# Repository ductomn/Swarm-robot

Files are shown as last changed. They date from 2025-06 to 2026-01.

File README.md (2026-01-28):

# Swarm Robot Platform

A low-cost, scalable swarm robotic platform designed for research and educational purposes, capable of infrared (IR)-based communication and basic cooperative behaviors.

Playlist of videos showcasing robots and algorithms: https://www.youtube.com/playlist?list=PLNTM9zCJujTltedypfpow2rPiPkVAqfGI

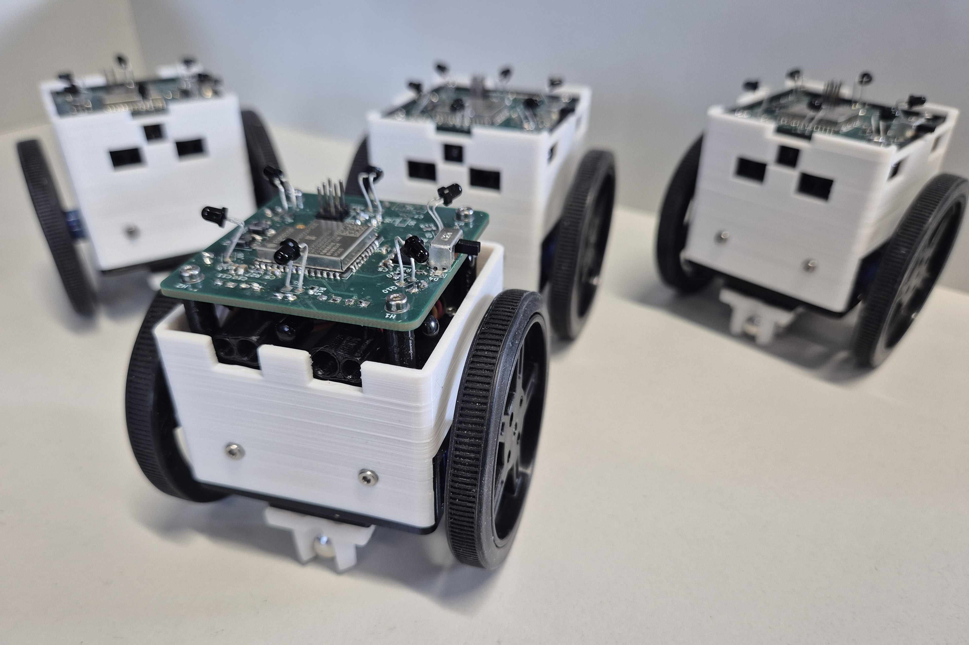
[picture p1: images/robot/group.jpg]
Swarm Robot


---

## 🧠 About the Project

This project focuses on the design of a **cooperative robotic platform** built around the ESP32 microcontroller. The primary goal is to enable simple, local communication and decentralized coordination among identical robots, forming a **swarm**.

**Key design constraints:**
- Minimal production cost (~24 EUR/robot, parts only)
- Compact and robust mechanical design
- Infrared-based full-duplex communication (360°)
- Modular and scalable C firmware using ESP-IDF
- Developed as part of a Bachelor’s Thesis at Brno University of Technology

> **Thesis Title:**  
> *Návrh a realizace kooperativní robotické platformy s jednoduchou komunikací*  
> (*Design and Implementation of a Cooperative Robotic Platform with Simple Communication*)

---

## ⚙️ Features

### 🔁 360° IR Communication
6 pairs of IR LEDs and phototransistors evenly placed around the robot enable full directional communication.

### 🚧 Obstacle Detection
2 front-facing IR LED + phototransistor pairs detect obstacles.

### 🤖 Cooperative Algorithms

#### With Leader
- Simulates a robot "calling" others to complete a task.
- Modified CSMA/CA protocol ensures robots check for ongoing transmissions before broadcasting.
- Robots walk randomly looking for signals:
  - If signal is found in a randomly chosen time window → the robot becomes a **follower**.
  - If not → the robot becomes a **leader**.
- **Leader** can be pre-set (WITH_LEADER 1)

- **Flowchart of system with leader:**

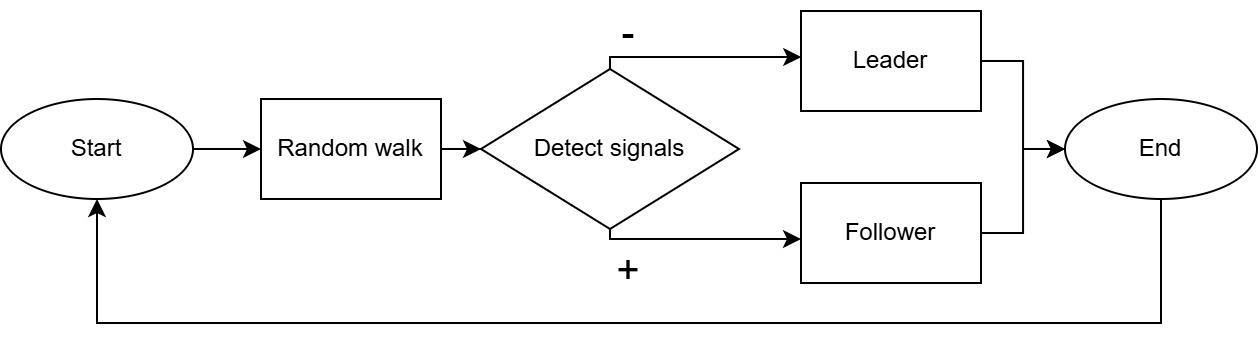
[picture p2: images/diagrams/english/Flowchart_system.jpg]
Flowchart


- **Implemented algorithms:**

  - **Follow**  
    Followers track the leader, who moves randomly.  
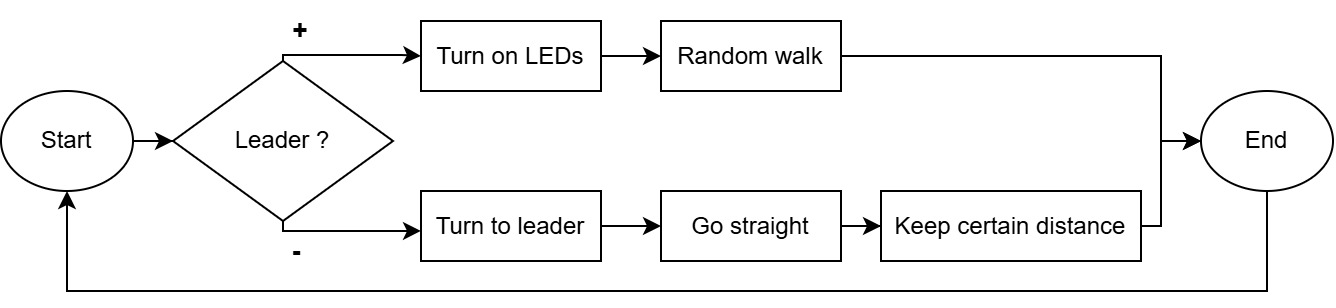
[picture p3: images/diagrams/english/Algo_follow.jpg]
Follow
    
  
  - **Spread Out**  
    Leader stays in place and acts as a beacon. Followers spread and return.  
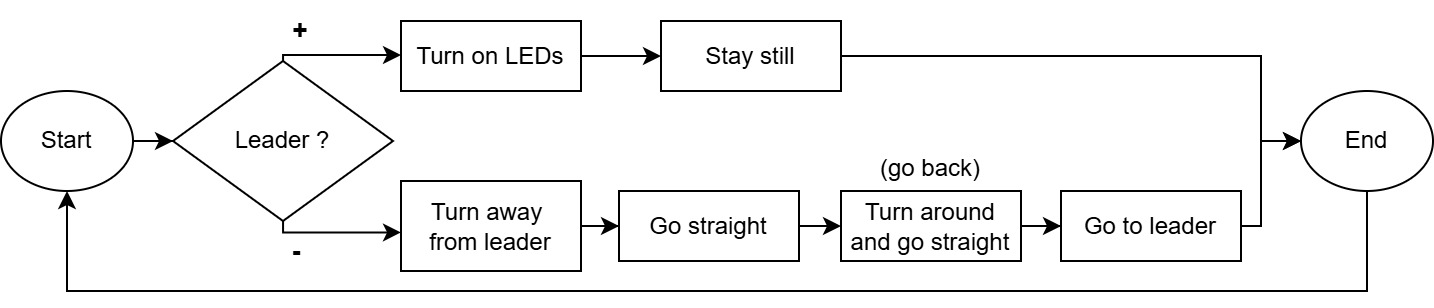
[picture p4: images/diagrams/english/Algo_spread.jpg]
Spread
    

#### Without Leader
- No signal detection or leader election.
- Algorithms run immediately after power-on.
  
- **Implemented algorithms:**

  - **Follow Chain**  
    Robots follow each other in a line. First robot walks randomly. Predefined or dynamic ID (order) assignment.  
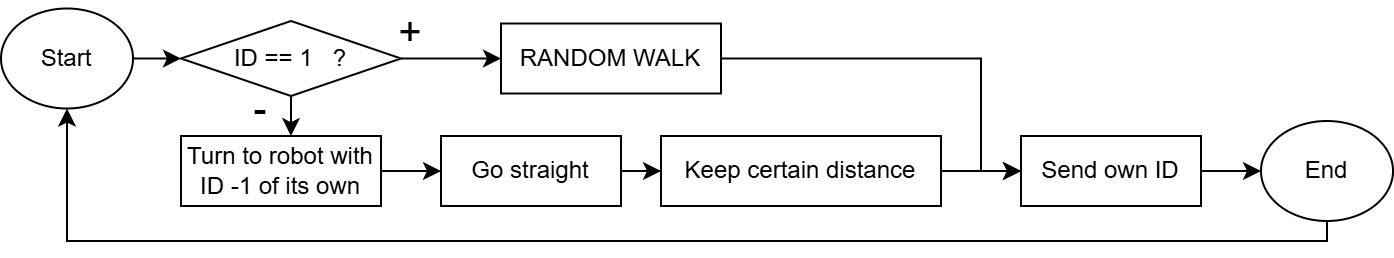
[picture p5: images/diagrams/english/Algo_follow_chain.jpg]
Follow Chain
    
  
  - **Chain**  
    Robots stay still in a line. The last robot moves forward to the front.  
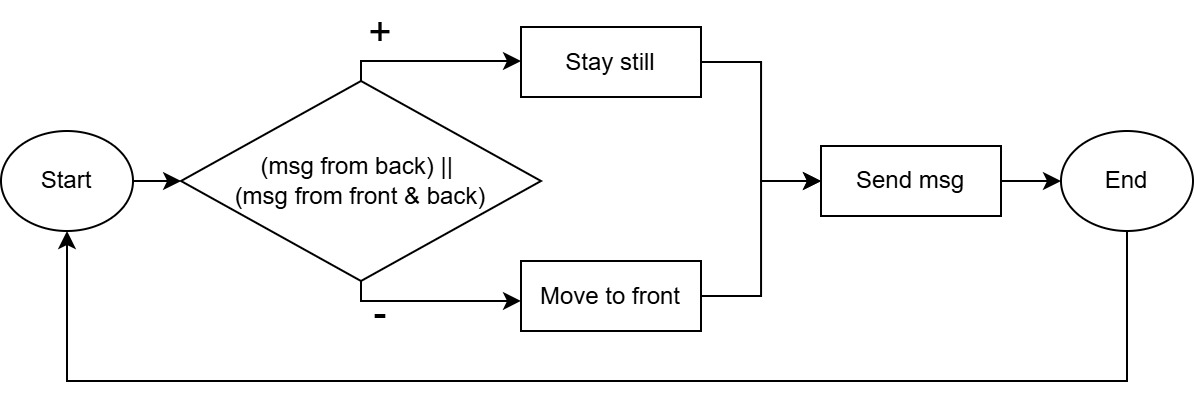
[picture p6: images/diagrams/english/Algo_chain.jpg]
Chain
    

### 🧠 FSM-Controlled Behavior

Each robot uses a finite state machine (FSM) for autonomous control and decision-making. The diagram shows the flow of states of algorithms with leader.  

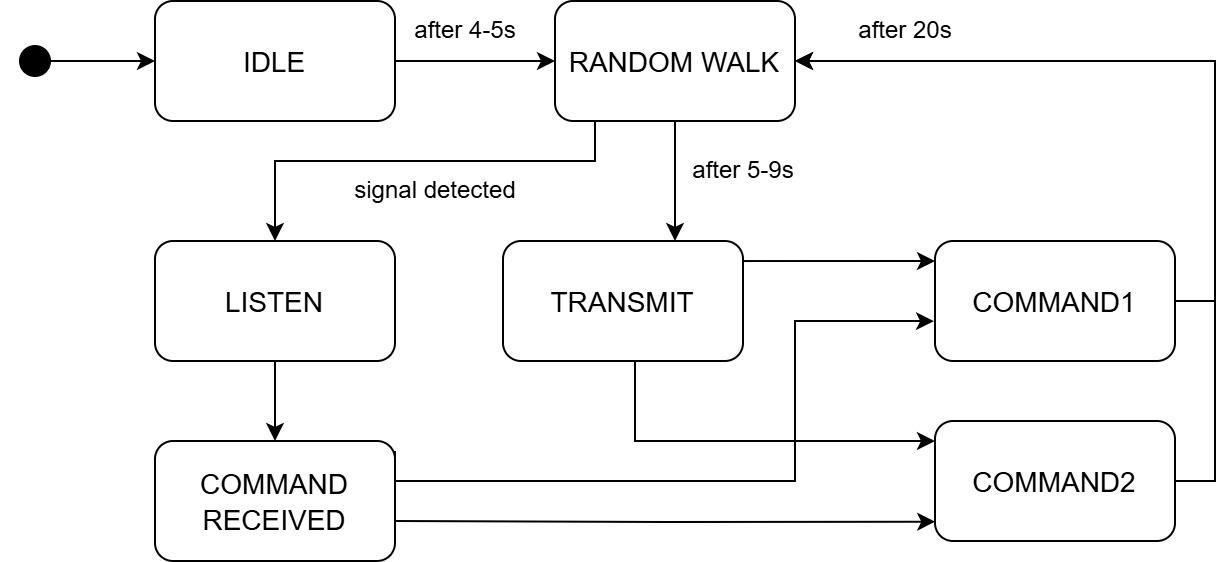
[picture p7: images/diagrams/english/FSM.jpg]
FSM Diagram


### 🔧 Firmware Modules

- `io_define` – I/O pin mappings, robot ID
- `servo_driver` – movement (servo) control
- `led_driver` – IR LED driver
- `hwtimer` – Hardware timer driver
- `adc_lib` – ADC driver
- `dm_comm` – IR communication (Manchester encoding, CSMA/CA)
- `coop` – Cooperative algorithm logic
- `state_machine` – FSM and behavior transitions

---

## 🛠️ Setting Up

### Requirements

- [ESP-IDF](https://docs.espressif.com/projects/esp-idf/en/latest/esp32/)
- PlatformIO (recommended; VS Code plugin)  
  Target board: `ESP32DOIT-DEVKIT-V1`
- USB-to-UART bridge (e.g. CP2102)

### 🔧 Calibration  

- **Movement Calibration**  
  The robot doesn’t use encoders, so the motors may spin at different speeds, causing drift.  
  Adjust `SERVO_FORWARD_LEFT_MOD` and `SERVO_BACKWARDS_RIGHT_MOD` in `io_define.h` to straighten movement.

- **IR Signal Thresholds**  
  Tune `SIG_THRESHOLD` in `dm_comm.h` and `DIS_THRESHOLD` in `coop.h` to adjust signal sensitivity.

- **Algorithm Selection**  
  Some algorithms (like **Chain** or **Follow Chain**) should start immediately on power-up.  
  Define the startup behavior by setting flags to "1" (`CHAIN` or `FOLLOW_CHAIN`).

### ⚡ Flashing Instructions  

1. Connect the robot to your computer via USB.
2. Open `io_define.h` and set:
   - `ROBOT_ID` – unique number per robot
   - `WITH_LEADER` – `1` (for pre-set leader - ID1) or `0`
   - `CHAIN` or `FOLLOW_CHAIN` – chosen algorithm
3. Build and flash the firmware

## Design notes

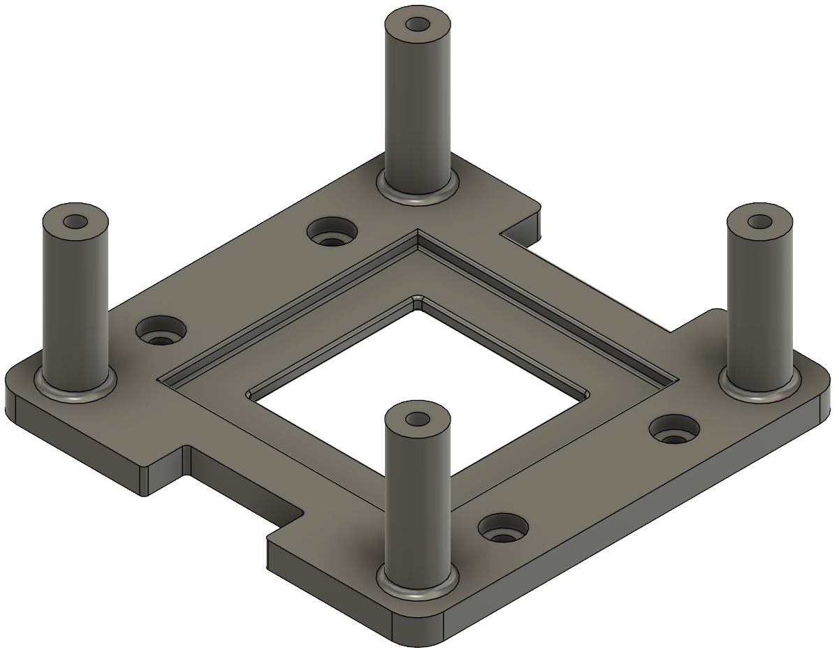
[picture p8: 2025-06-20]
images/robot/robot_Chassis_top v10.png

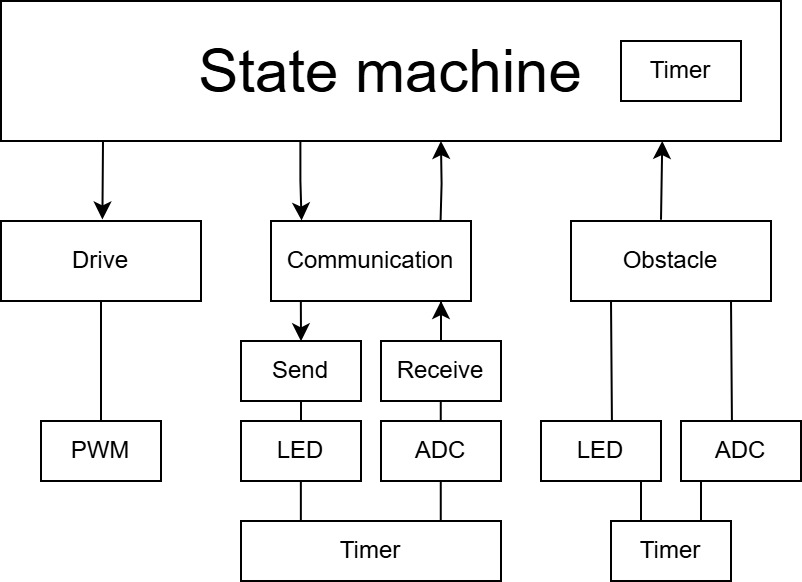
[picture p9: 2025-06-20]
images/diagrams/english/Software_architecture.jpg

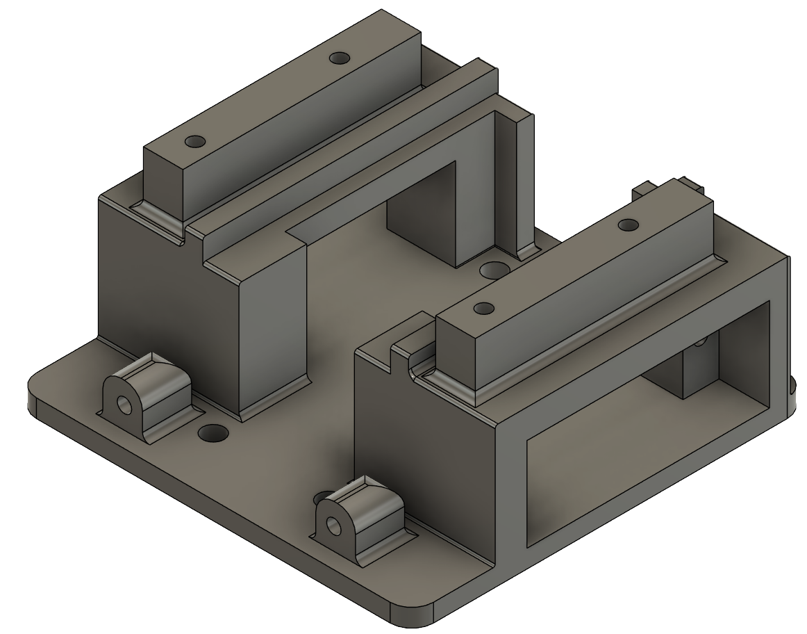
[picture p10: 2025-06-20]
images/robot/robot_Chassis_bottom.png

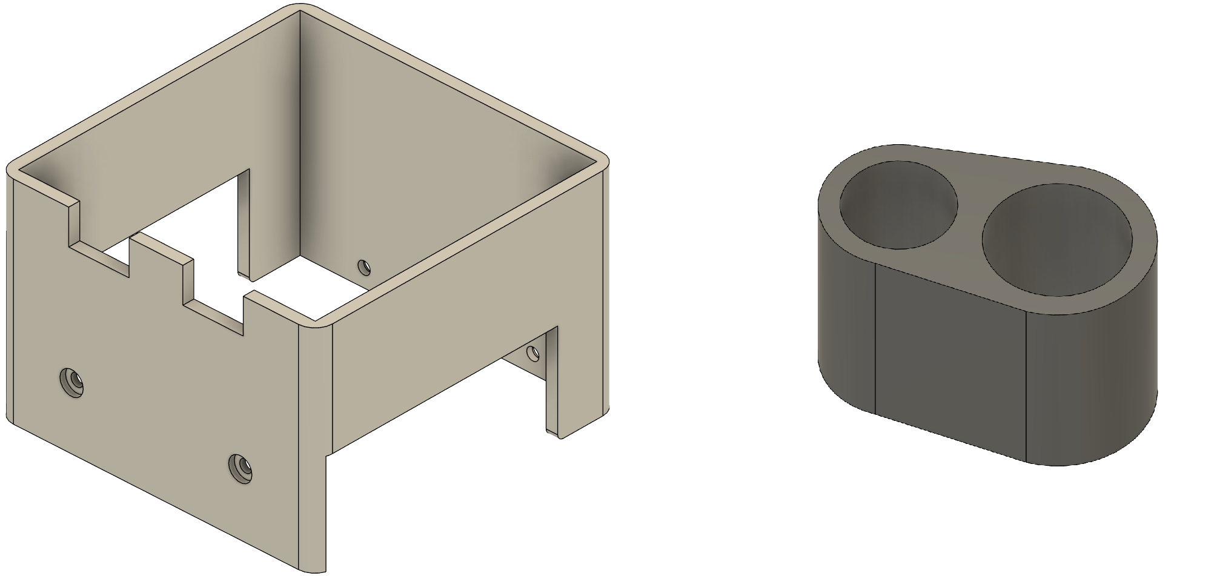
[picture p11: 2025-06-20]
images/robot/cover_LED_bottom.png

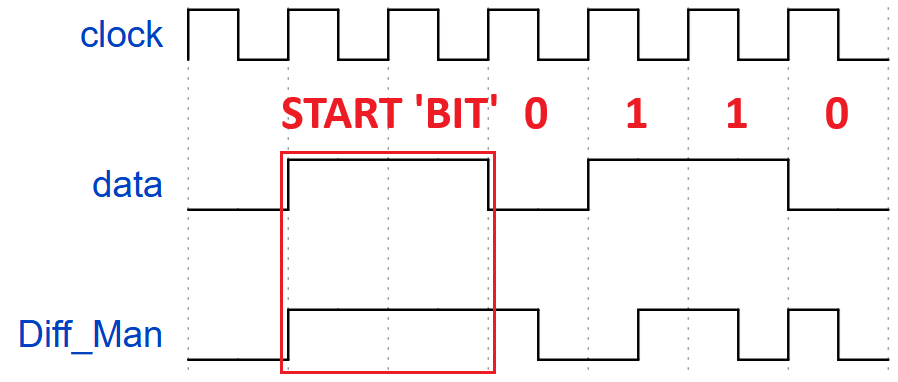
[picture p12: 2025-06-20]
images/diagrams/diff_man.png

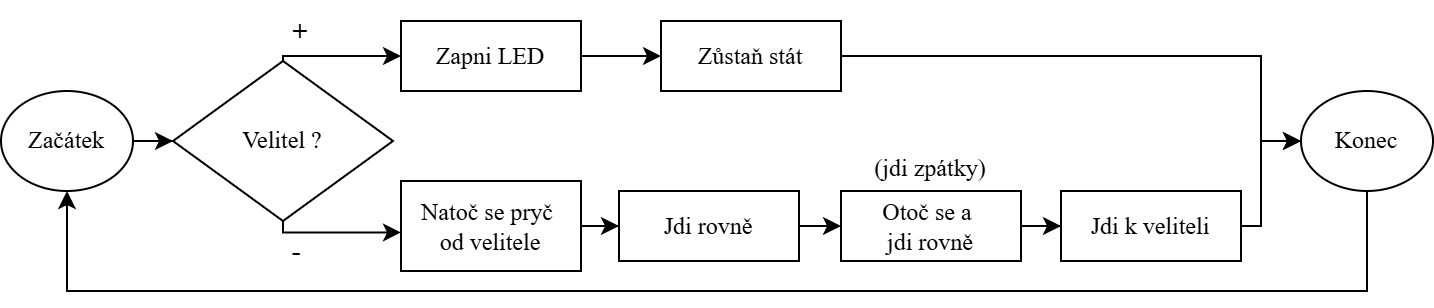
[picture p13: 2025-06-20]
images/diagrams/czech/Algo_spread.jpg

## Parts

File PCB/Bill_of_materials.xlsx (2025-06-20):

Reference | Value | Datasheet | Footprint | Qty | DNP | Total
C1,C2 | 22uF | ~ | Capacitor_SMD:C_1210_3225Metric_Pad1.33x2.70mm_HandSolder | 2 | x | #VALUE! | Laskakit
C3,C4,C7 | 10uF | ~ | -- mixed values -- | 3 | x+C7 | C7 | Hadex
C5,C6 | 0.1uF | ~ | Capacitor_SMD:C_0603_1608Metric_Pad1.08x0.95mm_HandSolder | 2 | 1 | 2
Comms1 | Jumper lišta |  | Connector_PinHeader_2.54mm:PinHeader_2x03_P2.54mm_Vertical | 1 | 3 | 3
D1 | D_Schottky | ~ | Diode_SMD:D_SMC | 1 | x | 0
D2 | LED_Blue? | ~ | LED_SMD:LED_0603_1608Metric | 1 | 0.8 | 0.8
D3 | LED_RED | ~ | LED_SMD:LED_0603_1608Metric | 1 | x | 0
D4 | LED_GREEN | ~ | LED_SMD:LED_0603_1608Metric | 1 | x | 0
IR0,IR1,IR2,IR3,IR4,IR5,IR6,IR7,IR8,IR9 | IR333C | ~ | LED_THT:LED_D1.8mm_W3.3mm_H2.4mm | 10 | 3 | 30
J1 | Li-Po 3.7V_1000mAh? |  | Connector_JST:JST_PH_S2B-PH-SM4-TB_1x02-1MP_P2.00mm_Horizontal | 1 | 99 | 99
J2,J3 | Motor | ~ | Personal:Cable_connector_WJ500V-5.08-2P | 2 | 17 | 34
L1 | 4.7uH | ~ | Inductor_SMD:L_Chilisin_BMRx00060630 | 1 | x | 0
Q1,Q12 | SI2312CDS | ~ | Package_TO_SOT_SMD:SOT-23 | 2 | 3.8 | 7.6
Q2,Q3,Q4,Q5,Q6,Q7,Q8,Q9,Q10,Q11 | PT334 | https://www.rcscomponents.kiev.ua/datasheets/bpw40.pdf | LED_THT:LED_D1.8mm_W3.3mm_H2.4mm | 10 | 3 | 30
R1 | 16k | ~ | Capacitor_SMD:C_0603_1608Metric_Pad1.08x0.95mm_HandSolder | 1 | x | 0
R2 | 2k2 | ~ | Capacitor_SMD:C_0603_1608Metric_Pad1.08x0.95mm_HandSolder | 1 | x | 0
R3 | 220 | ~ | Resistor_SMD:R_0603_1608Metric_Pad0.98x0.95mm_HandSolder | 1 | 0.8 | 0.8
R4 | 1k2 | ~ | Capacitor_SMD:C_0603_1608Metric_Pad1.08x0.95mm_HandSolder | 1 | x | 0
R5,R6 | 1k | ~ | Capacitor_SMD:C_0603_1608Metric_Pad1.08x0.95mm_HandSolder | 2 | x | 0
R7,R8,R9,R10,R11,R12,R13,R14 | 39 | ~ | Resistor_SMD:R_0603_1608Metric_Pad0.98x0.95mm_HandSolder | 8 |  | 0
R15,R29 | 100 | ~ | Resistor_SMD:R_0603_1608Metric_Pad0.98x0.95mm_HandSolder | 2 | 0.8 | 1.6
R16,R30 | 47k | ~ | Resistor_SMD:R_0603_1608Metric_Pad0.98x0.95mm_HandSolder | 2 | 0.8 | 1.6
R17,R18,R19,R20,R21,R22,R23,R24,R25,R26 | 4k7 | ~ | Resistor_SMD:R_0603_1608Metric_Pad0.98x0.95mm_HandSolder | 10 | 0.8 | 8
R27,R28 | 20 | ~ | Resistor_SMD:R_0603_1608Metric_Pad0.98x0.95mm_HandSolder | 2 |  | 0
SW1 | SW_SPST | ~ | Connector_PinHeader_2.54mm:PinHeader_1x02_P2.54mm_Vertical | 1 |  | 0
U2 | TB6612FNG | https://toshiba.semicon-storage.com/us/product/linear/motordriver/detail.TB6612FNG.html | Package_SO:SSOP-24_5.3x8.2mm_P0.65mm | 1 | 122 | 122
U3 | MT3608 | https://www.olimex.com/Products/Breadboarding/BB-PWR-3608/resources/MT3608.pdf | Package_TO_SOT_SMD:SOT-23-6 | 1 | 9 | 9
U4 | TP4056 | https://eu.mouser.com/datasheet/2/830/TP4056-2487427.pdf | Package_SO:SOP-8_3.9x4.9mm_P1.27mm | 1 | 9 | 9
U1 | module_ESP32 |  | Personal:ESP32-NodeMCU | 1 | 198 | 198 | chip_ESP32 | chip_ESP32
 |  |  |  |  |  | 556.4 | ams1117 | ams1117
 |  |  |  |  |  |  | cp2102 | CH340
 |  |  |  |  |  |  | další věci | další věci

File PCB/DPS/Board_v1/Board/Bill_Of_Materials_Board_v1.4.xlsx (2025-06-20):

Reference | Value | Datasheet | Footprint | Qty | DNP | Total
C1,C2 | 22uF | ~ | -- mixed values -- | 2 | x | 0 |  | Laskakit
L1 | 4.7uH | ~ | Inductor_SMD:L_Chilisin_BMRx00060630 | 1 | x | 0 |  | Mouser
D1 | D_Schottky | ~ | Diode_SMD:D_SMC | 1 | x | 0
J2 | USB_B_Micro | ~ | Connector_USB:USB_Micro-B_Amphenol_10118194-0001LF_Horizontal | 1 | x | 0
R22 | 2k2 | ~ | Capacitor_SMD:C_0603_1608Metric_Pad1.08x0.95mm_HandSolder | 1 | x | 0 |  | TOTAL:
U1 | MT3608 | https://www.olimex.com/Products/Breadboarding/BB-PWR-3608/resources/MT3608.pdf | Package_TO_SOT_SMD:SOT-23-6 | 1 | x | 0 |  |  | 610.249
C3,C4 | 10uF | ~ | -- mixed values -- | 2 | x | 0
R23 | 1k2 | ~ | Capacitor_SMD:C_0603_1608Metric_Pad1.08x0.95mm_HandSolder | 1 | x | 0
R24,R25 | 1k | ~ | -- mixed values -- | 2 | x | 0
D2 | LED_RED | ~ | LED_SMD:LED_0603_1608Metric_Pad1.05x0.95mm_HandSolder | 1 | x | 0
D3 | LED_GREEN | ~ | LED_SMD:LED_0603_1608Metric_Pad1.05x0.95mm_HandSolder | 1 | x | 0
U2 | TP4056 | https://eu.mouser.com/datasheet/2/830/TP4056-2487427.pdf | Package_SO:SOP-8_3.9x4.9mm_P1.27mm | 1 | 18 | 18
C5, C6 | 10uF | ~ | 0603_1608 | 2 | 1.13 | 2.26 | x
C7,C8,C9,C11 | 0.1uF | ~ | Capacitor_SMD:C_0603_1608Metric_Pad1.08x0.95mm_HandSolder | 4 | 0.376 | 1.504 | x
C10 | 22uF | ~ | Capacitor_SMD:C_0603_1608Metric_Pad1.08x0.95mm_HandSolder | 1 | 1.75 | 1.75 | x
Comms1 | ~ |  | Connector_PinHeader_2.54mm:PinHeader_2x03_P2.54mm_Vertical | 1 | 3 | 3
D6 | ESD5Z5.0T1G | https://www.onsemi.com/pdf/datasheet/esd5z2.5t1-d.pdf | Diode_SMD:D_SOD-523 | 1 | 3.33 | 3.33 | x
D5 | 1N5819HW-7-F | ~ | Diode_SMD:D_SOD-123 | 1 | 5.96 | 5.96 | x
D4 | LED | ~ | LED_SMD:LED_0603_1608Metric_Pad1.05x0.95mm_HandSolder | 1 | 0.8 | 0.8 | x
IR1,IR2 | SFH4544 | ~ | LED_THT:LED_D1.8mm_W3.3mm_H2.4mm | 2 | 13.33 | 26.66 | x
IR3,IR4,IR5,IR6,IR7,IR8 | SFH4547 | ~ | LED_THT:LED_D1.8mm_W3.3mm_H2.4mm | 6 | 6.57 | 39.42 | x
J1 | Li-Po 3.7V_1000mAh |  | Connector_JST:JST_PH_S2B-PH-SM4-TB_1x02-1MP_P2.00mm_Horizontal | 1 | 99 | 99 | x
 | Konektor _Baterie |  |  | 1 | 2 | 2 | x
M1,M2 | Servo_Motor SG90 | ~ |  | 2 | 60 | 120 | x
 | Konektor |  | Connector_PinHeader_2.54mm:PinHeader_1x03_P2.54mm_Vertical | 2 | 0.8 | 1.6
Q5,Q6,Q7,Q8,Q9,Q10 | TEFT4300 | https://www.rcscomponents.kiev.ua/datasheets/bpw40.pdf | LED_THT:LED_D1.8mm_W3.3mm_H2.4mm | 6 | 9.3 | 55.8 | x
Q1,Q2 | 304PTD4B-1A |  |  | 2 | 2.8 | 5.6
Q3,Q4 | SI2312CDS | ~ | Package_TO_SOT_SMD:SOT-23 | 2 | 3.8 | 7.6 | x
R1,R2,R15,R16,R17,R18,R19,R20 | 4k7 | ~ | Resistor_SMD:R_0603_1608Metric_Pad0.98x0.95mm_HandSolder | 8 | 0.376 | 3.008 | x
R3,R4,R7,R8,R9,R10,R11,R12 | 39 | ~ | Resistor_SMD:R_0603_1608Metric_Pad0.98x0.95mm_HandSolder | 8 | 0.326 | 2.608 | x
R5,R13 | 100 | ~ | Resistor_SMD:R_0603_1608Metric_Pad0.98x0.95mm_HandSolder | 2 | 0.2 | 0.4 | x
R6,R14 | 47k | ~ | Resistor_SMD:R_0603_1608Metric_Pad0.98x0.95mm_HandSolder | 2 | 0.226 | 0.452 | x
R21 | 16k | ~ | Capacitor_SMD:C_0603_1608Metric_Pad1.08x0.95mm_HandSolder | 1 | 0.2 | 0 | x
R27 | 10k | ~ | Resistor_SMD:R_0603_1608Metric_Pad0.98x0.95mm_HandSolder | 1 | 0.301 | 0.301 | x
R26 | 5k1 | ~ | Resistor_SMD:R_0603_1608Metric_Pad0.98x0.95mm_HandSolder | 1 | 0.326 | 0.326 | x
SW1 | SLW-864574-5A-RA-N-D | ~ | Button_Switch_THT:SW_Slide_SPDT_Straight_CK_OS102011MS2Q | 1 | 7.87 | 7.87 | x
SW2,SW3 | TS-1088R-02026 | ~ | 0_Custom_Footprints:SW_Tactile_TS-1088R-02026 | 2 | 3 | 6 | x
U3 | AMS1117-3.3 | http://www.advanced-monolithic.com/pdf/ds1117.pdf | Package_TO_SOT_SMD:SOT-223-3_TabPin2 | 1 | 3 | 3 | x
U4 | ESP32-WROOM-32UE | https://www.espressif.com/sites/default/files/documentation/esp32-wroom-32e_esp32-wroom-32ue_datasheet_en.pdf | RF_Module:ESP32-WROOM-32D | 1 | 68 | 68 | x
kolo sg90 |  |  |  | 2 | 38 | 76 | x
podperné kolo |  |  |  | 2 | 24 | 48 | x
 |  |  |  | 82

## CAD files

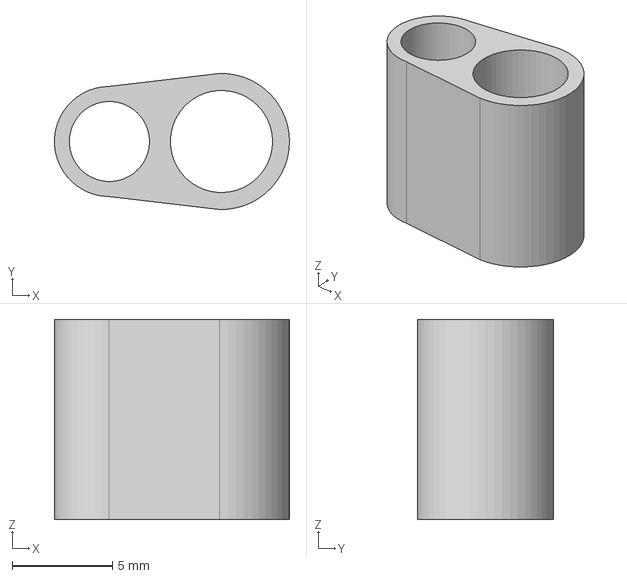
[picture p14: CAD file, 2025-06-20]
3D_model/LED_cover_both.step
11.7 x 6.80 x 10.0 mm

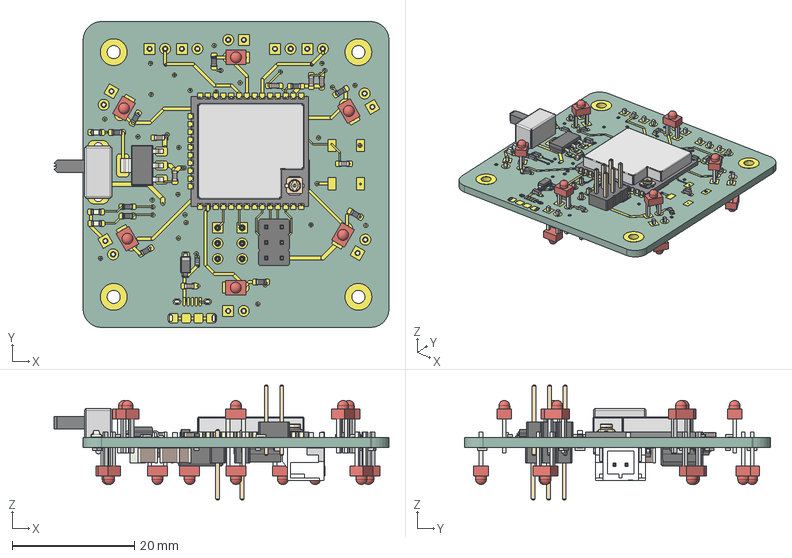
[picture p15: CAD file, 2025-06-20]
PCB/DPS/Board_v1/Board/Board.step
54.8 x 50.0 x 18.8 mm
LED_0603_1608Metric x 3
C_0603_1608Metric x 7
D_SOD_523
R_0603_1608Metric x 27
SOT_223
LED_D1.8mm_W3.3mm_H2.4mm x 16
D_SOD_123
ESP32-WROOM-32U
PinHeader_2x03_P254mm_Vertical
SLW-864574-5A-RA-N-D
CQ assembly
C_1210_3225Metric x 4
SOT_23 x 2
D_SMC
JST - PH - SMD (R) - 2Pin - 2.00mm
PinHeader_1x03_P254mm_Vertical x 2
SOT_23_6
Board_track_1
Board_track_2
Board_track_3
Board_track_4
Board_track_5
Board_track_6
Board_track_7
Board_track_8
Board_track_9
Board_track_10
Board_track_11
Board_track_12
Board_track_13
Board_track_14
Board_track_15
Board_track_16
Board_track_17
Board_track_18
Board_track_19
Board_track_20
Board_track_21
Board_track_22
Board_track_23
Board_track_24
Board_track_25
Board_track_26
Board_track_27
Board_track_28
Board_track_29
Board_track_30
Board_track_31
Board_track_32
Board_track_33
Board_track_34
Board_track_35
Board_track_36
Board_track_37
Board_track_38
Board_track_39
Board_track_40
Board_track_41
Board_track_42
Board_track_43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

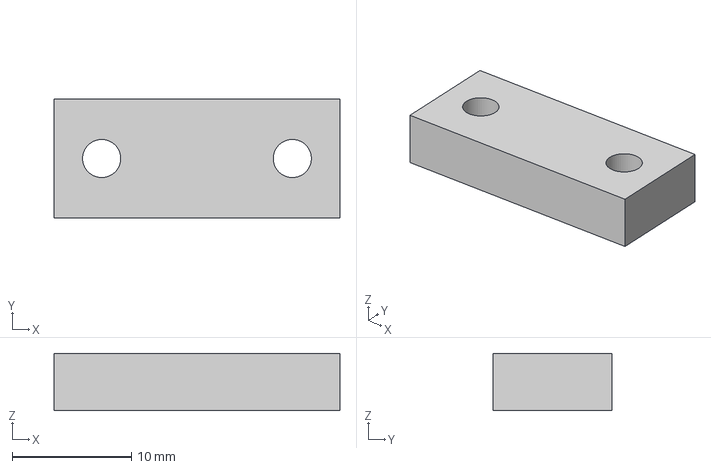
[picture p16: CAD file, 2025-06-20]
3D_model/Castor_support.step
24.0 x 10.0 x 4.80 mm

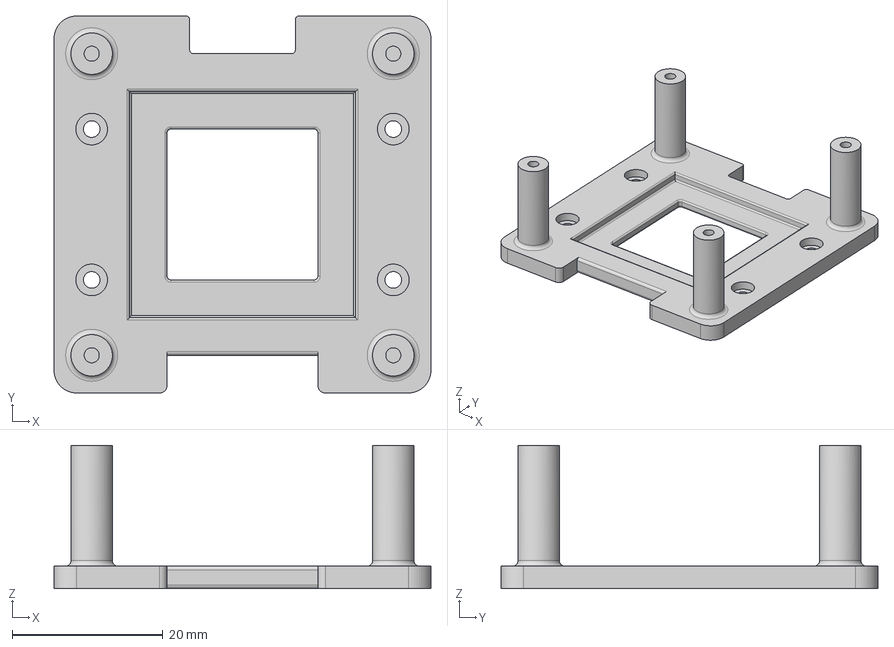
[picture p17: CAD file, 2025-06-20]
3D_model/Chassis_top.step
50.0 x 50.0 x 19.0 mm

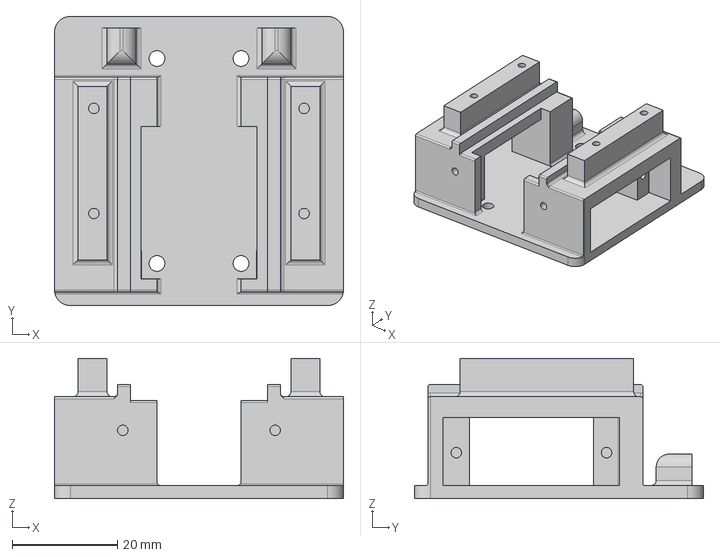
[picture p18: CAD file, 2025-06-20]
3D_model/Chassis_bottom.step
55.0 x 55.0 x 26.7 mm

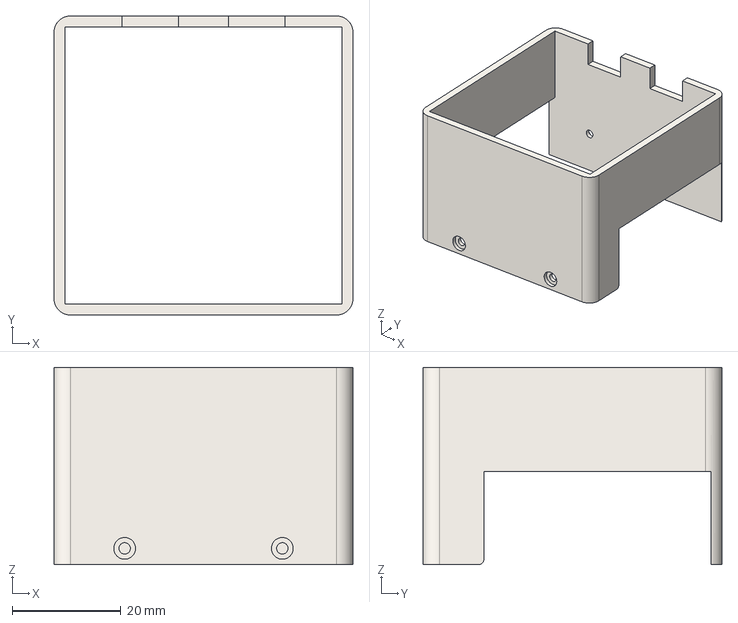
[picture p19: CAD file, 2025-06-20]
3D_model/Cover_bottom_without_LED.step
55.0 x 55.0 x 36.3 mm

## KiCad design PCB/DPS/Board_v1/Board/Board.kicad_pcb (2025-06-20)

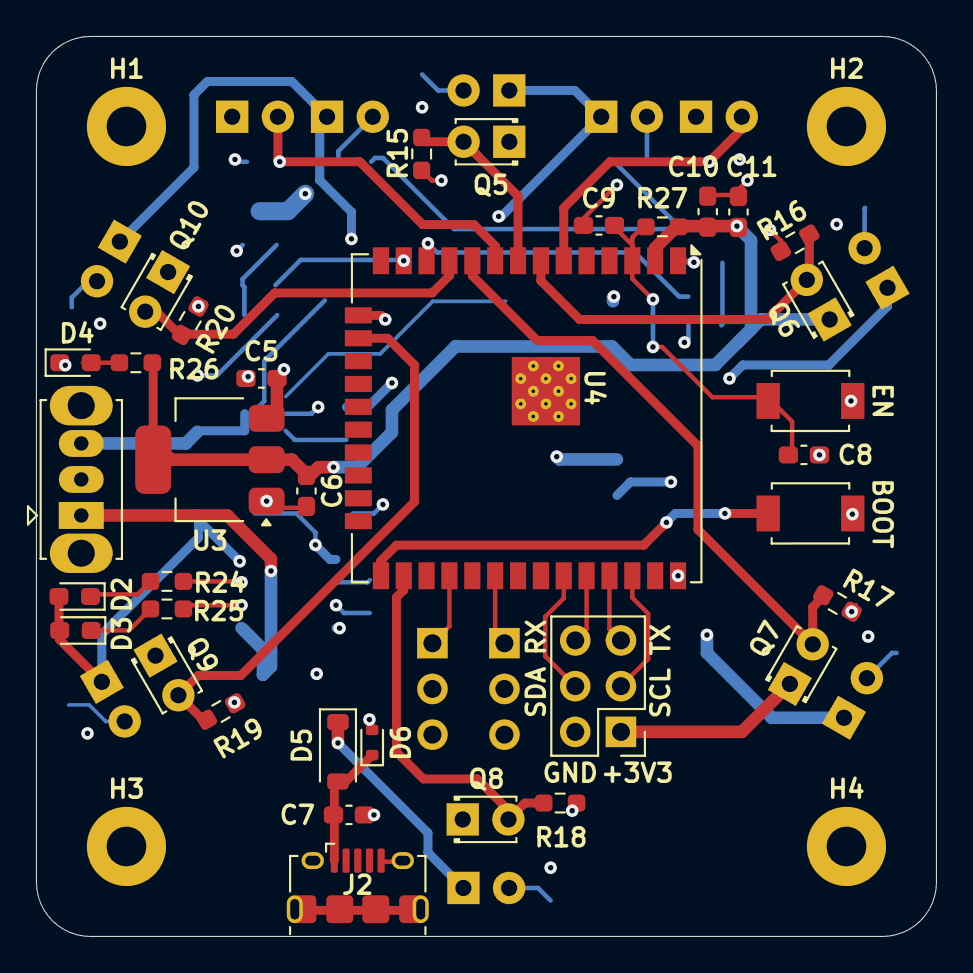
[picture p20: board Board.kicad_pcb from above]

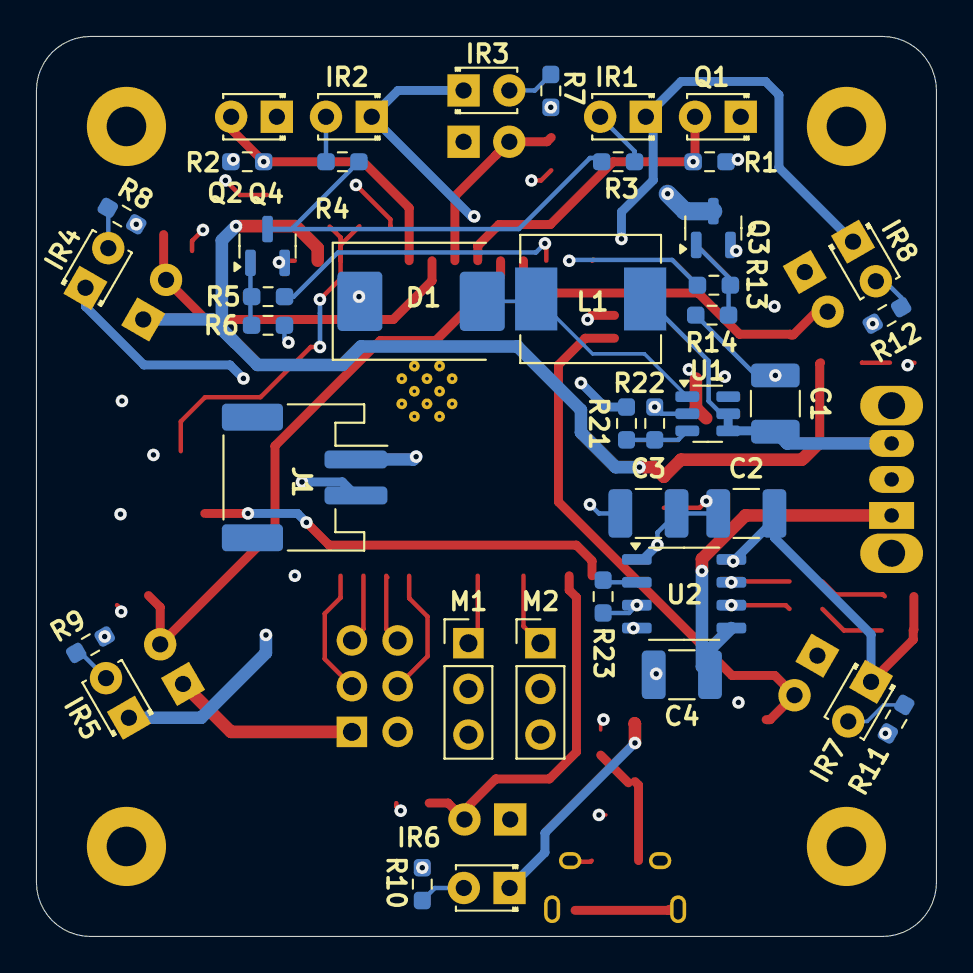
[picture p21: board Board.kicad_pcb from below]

Board: 4 copper layers, 50.0 x 50.0 mm, 79 parts (40 on the bottom side), 45 nets.

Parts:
BOOT: TS-1088R-02026; SW_Tactile_TS-1088R-02026
C1, C2: 22uF; C_1210_3225Metric_Pad1.33x2.70mm_HandSolder
C3, C4: 10uF; C_1210_3225Metric_Pad1.33x2.70mm_HandSolder
C5, C6: 10uF; C_0603_1608Metric_Pad1.08x0.95mm_HandSolder
C7, C8, C9, C11: 0.1uF; C_0603_1608Metric_Pad1.08x0.95mm_HandSolder
C10: 22uF; C_0603_1608Metric_Pad1.08x0.95mm_HandSolder
Comms1: PinHeader_2x03_P2.54mm_Vertical
D1: D_Schottky; D_SMC
D2: LED_RED; LED_0603_1608Metric_Pad1.05x0.95mm_HandSolder
D3: LED_GREEN; LED_0603_1608Metric_Pad1.05x0.95mm_HandSolder
D4: LED; LED_0603_1608Metric_Pad1.05x0.95mm_HandSolder
D5: 1N5819HW-7-F; D_SOD-123
D6: ESD5Z5.0T1G; D_SOD-523
EN: TS-1088R-02026; SW_Tactile_TS-1088R-02026
H1, H2, H3, H4: MountingHole_Pad; MountingHole_2.2mm_M2_Pad
IR1, IR2: SFH4544; LED_D1.8mm_W3.3mm_H2.4mm
IR3, IR4, IR5, IR6, IR7, IR8: OED-EL-1L2; LED_D1.8mm_W3.3mm_H2.4mm
J1: Li-Po 3.7V; JST_PH_S2B-PH-SM4-TB_1x02-1MP_P2.00mm_Horizontal
J2: USB_B_Micro; USB_Micro-B_Amphenol_10118194_Horizontal
L1: 4.7uH; L_Chilisin_BMRx00060630
M1, M2: SG90; PinHeader_1x03_P2.54mm_Vertical
Q1, Q2, Q5, Q6, Q7, Q8, Q9, Q10: TEFT4300; LED_D1.8mm_W3.3mm_H2.4mm
Q3, Q4: SI2312CDS; SOT-23
R1, R2, R15, R16, R17, R18, R19, R20: 4k7; R_0603_1608Metric_Pad0.98x0.95mm_HandSolder
R3, R4, R7, R8, R9, R10, R11, R12: 39; R_0603_1608Metric_Pad0.98x0.95mm_HandSolder
R5, R13: 100; R_0603_1608Metric_Pad0.98x0.95mm_HandSolder
R6, R14: 47k; R_0603_1608Metric_Pad0.98x0.95mm_HandSolder
R21: 16k; R_0603_1608Metric_Pad0.98x0.95mm_HandSolder
R22: 2k2; R_0603_1608Metric_Pad0.98x0.95mm_HandSolder
R23: 1k2; R_0603_1608Metric_Pad0.98x0.95mm_HandSolder
R24, R25: 1k; R_0603_1608Metric_Pad0.98x0.95mm_HandSolder
R26: 5k1; R_0603_1608Metric_Pad0.98x0.95mm_HandSolder
R27: 10k; R_0603_1608Metric_Pad0.98x0.95mm_HandSolder
SW1: SLW-864574-5A-RA-N-D; SW_Slide_SPDT_Straight_CK_OS102011MS2Q
U1: MT3608; SOT-23-6
U2: TP4056; SOP-8_3.9x4.9mm_P1.27mm
U3: AMS1117-3.3; SOT-223-3_TabPin2
U4: ESP32-WROOM-32UE

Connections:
+3V3: C6.1, C10.1, C11.1, Comms1.1 (VCC), Q1.1 (C), Q2.1 (C), Q5.1 (C), Q6.1 (C), Q7.1 (C), Q8.1 (C), Q9.1 (C), Q10.1 (C), R26.1, R27.1, U3.2 (VO), U4.2 (VDD)
+5V: C2.1, C3.1, C5.1, D1.1 (K), D2.2 (A), D3.2 (A), D5.1 (K), IR1.1 (K), IR2.1 (K), IR3.1 (K), IR4.1 (K), IR5.1 (K), IR6.1 (K), IR7.1 (K), IR8.1 (K), M1.2 (+), M2.2 (+), R21.1, U2.4 (VCC), U2.8 (CE), U3.3 (VI)
/ESP32/EN: C8.1, C9.1, EN.2, R27.2, U4.3 (EN)
/ESP32/IO0_BTN: BOOT.2, U4.25 (IO0)
A0: Q5.2 (E), R15.2, U4.8 (IO32)
A1: Q6.2 (E), R16.2, U4.7 (IO35)
A2: Q7.2 (E), R17.2, U4.10 (IO25)
A3: Q8.2 (E), R18.2, U4.26 (IO4)
A4: Q9.2 (E), R19.2, U4.16 (IO13)
A5: Q10.2 (E), R20.2, U4.11 (IO26)
A8_DIS: Q1.2 (E), R1.2, U4.9 (IO33)
A9_DIS: Q2.2 (E), R2.2, U4.6 (IO34)
CHRG_B+: C4.1, SW1.1 (A), U2.5 (BAT)
GND: BOOT.1, C1.2, C2.2, C3.2, C4.2, C5.2, C6.2, C7.2, C8.2, C9.2, C10.2, C11.2, Comms1.2 (GND), D4.1 (K), D6.2 (A), EN.1, H1.1, H2.1, H3.1, H4.1, J1.2, J2.5 (GND), J2.6 (Shield), M1.3 (-), M2.3 (-), Q3.2 (S), Q4.2 (S), R1.1, R2.1, R6.1, R14.1, R15.1, R16.1, R17.1, R18.1, R19.1, R20.1, R22.2, R23.1, U1.2 (GND), U2.1 (TEMP), U2.3 (GND), U3.1 (GND), U4.1 (GND), U4.15 (GND), U4.38 (GND), U4.39 (GND)
IR_DIS: R5.1, U4.12 (IO27)
IR_SIG: R13.1, U4.13 (IO14)
IR_V: Q3.3 (D), R7.1, R8.1, R9.1, R10.1, R11.1, R12.1
IR_V_DIS: Q4.3 (D), R3.1, R4.1
unnamed: D1.2 (A), L1.2, U1.1 (SW)
unnamed: D2.1 (K), R24.2
unnamed: D3.1 (K), R25.2
unnamed: D4.2 (A), R26.2
unnamed: IR1.2 (A), R3.2
unnamed: IR2.2 (A), R4.2
unnamed: IR3.2 (A), R7.2
unnamed: IR4.2 (A), R8.2
unnamed: IR5.2 (A), R9.2
unnamed: IR6.2 (A), R10.2
unnamed: IR7.2 (A), R11.2
unnamed: IR8.2 (A), R12.2
unnamed: Q3.1 (G), R13.2, R14.2
unnamed: Q4.1 (G), R5.2, R6.2
unnamed: J1.1, SW1.2 (B)
unnamed: C1.1, L1.1, SW1.3 (C), U1.4 (EN), U1.5 (IN)
unnamed: R21.2, R22.1, U1.3 (FB)
unnamed: R24.1, U2.7 (CHRG)
unnamed: R23.2, U2.2 (PROG)
unnamed: R25.1, U2.6 (STDBY)
PWM_A: M1.1 (PWM), U4.30 (IO18)
PWM_B: M2.1 (PWM), U4.28 (IO17)
RX: Comms1.6 (TX), U4.34 (RXD0/IO3)
SCL: Comms1.3 (SCL), U4.36 (IO22)
SDA: Comms1.4 (SDA), U4.33 (IO21)
TX: Comms1.5 (RX), U4.35 (TXD0/IO1)
VBUS: C7.1, D5.2 (A), D6.1 (K), J2.1 (VBUS)

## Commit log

2025-05-23 Added 3D model
    [Castor_support.step, Chassis_bottom.step, Chassis_top.step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]
2025-05-23 Added PCB files
    [Bill_Of_Materials_Board_v1.4.xlsx, Bill_of_materials.xlsx, Bill_of_materials_default.csv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]
